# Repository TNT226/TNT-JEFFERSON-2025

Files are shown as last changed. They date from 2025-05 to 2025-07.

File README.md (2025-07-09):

# `TNT` - `KABOOM`

## Disclaimer
This repository is the same for the competition of the WRO 2025 Venezuela, and the WRO 2025 China.
There are two teams participating in the WRO competitions: one competing in WRO Venezuela made up of Nicola, Emiliana and Sara and another that will compete in WRO China made up of Nicola, Sara and Samantha.

## About

This repository provides information and knowledge regarding the current progress, evolution, and development of our self-driving robot vehicle for the World Robot Olympian (WRO) 2025 competition in the category Future Engineers, which is build and coded by us.

## TNT & Kaboom - WRO 2025 Future Engineers

The name of our team is TNT, we chose this name because we will _explode_ the comptetition with our hard work and dedication! On the other hand, Kaboom is the name of our autonomous robot, build by using 3d printing and arduino together. We are a group of Venezuelan high schoolers who yearn to learn and be masters in robotics. TNT also have plenty of objectives like:

* Obtain expertise and mastery in robotics, engineering and self-driven robots.
* Learning how to cooperate and work as a team to solve problems with ingenious, imaginative, and creative solutions.
* Acquire knowledge regarding new and old technologies, information about eletronics, hardware, software, and more.
* Gain experience for opportunities or competitions that we might face in the future.
* Win the competition and enjoy the process through this exciting road!

TNT is form by three members :

  - Nicola Pasquale Simone Perdomo 16YO
  - Sarah Virginia Quintana Arrieta 18YO
  - Emiliana Raquel Guerrero Fermín 16YO
  
One thing that defines us, TNT, is that unlike others, we _don't_ give up easily, we are determine to be the best and improve as much as possible, always looking for success and enjoying every part of the process. You can see this characteristic about us being really strong during "our journey, process and prototypes" below and in the `Older versions of our final robot` folder.

## Content

- `Pictures (Team and vehicle)`: contains photos of the final robot from different views and angles. And photos of us individually and in group.
- `Older versions of our final robot`: contains photos of our previous ideas and prototypes that eventually lead to the final design and robot, Kaboom.
- `Obstacle management`: contains the source code of the prototypes and the final robot with detailed comments, strategies, flowchart diagrams and pseudocode.
- `Videos`: contains links to our Youtube videos which show how our previous attempts turn out and function, and also how the final robot completes the challenges and more. 
- `Mobility management`: contains all the 3D printed models we used throught our journey, all the 3d pieces, electrical components, and materials used in the final robot, a brief discussion regarding the vehicle chassis design/selection as well as the mounting of all components to the vehicle chassis/structure, and more.
- `Power and sense management`: contains power and sense management about the power source for the vehicle as well as the sensors required to provide the vehicle with information to negotiate the different challenges, the reasons for selecting various sensors and how they are being used on the vehicle together and a wiring diagram with BOM that includes all aspects of professional wiring diagrams.

## Materials and components

What is Kaboom made of? Kaboom is made of pieces and blocks from a  aluminum alloy chassis and 3d printed parts from our 3d printer being the bambu lab P1S owned by Nicola Simone, while also using "ready to go" electrical components. We also used an Arduino UNO board as our main controller, since we saw that this is the most efficient way to complete the challenges.

|PIECES OUR ROBOT USES |3D PIECES/ARDUINO/ELECTRICAL COMPONENTS OUR ROBOT USES ARE:| 
|---|---|
|1x Yahboom DIY Smart Robot Chassis Ackerman Chassis|1x Gray 11.4V JGB37-520 Motor|
|1x Second Floor Platform 3d|1x Pixycam 2.1|
|1x Axis 3d|2x Ultrasound sensors|
|1x Carriage Axle Gear 3d| Arduino cables |
|1x Motor Gear|Alligator Cables|
|1x Motor Support 3d|1x Nihewo Batery 11.1V/7500mAh|
|1x Motor Support Stand 3d|1x Arduino Uno Board|
||1x Arduino Shield Protoboard|
||1x H-Bridge Module|
||1x Buck Module|
||1x Switch On-Off|

### To know the complete list of all the materials used visit the `Mobility management` folder.

## Our journey, progress and prototypes

In the beginning of our journey, we had plenty of various and diverse ideas on how to build our robot but eventually it all worked out. When we first started, we did messy sketches and tried a lot of ideas. Here are some of our first sketches and ideas for Terreneitor:



Eventually, with these sketches in mind, we started working on the physical robot. We had high hopes for our first prototype, and the more we worked on it, the more our hopes grew. But, there was a problem, a big one...if you see "First prototype wheels mechanism" (you can find in the `videos` folder) you might think, like us, that it would be super fast on the ground, however when we finally were ready to put it to the test... it failed. The wheels mechanism of this prototype did not work on the ground. We tried to change many things and pieces in this prototype to see if it would help, but all our work was in vain, the mechanism still did not work on the floor. Eventually, we find out the cause... the mechanism didn't work because the dc motor that we were using, eventhogh it was fast, it didn't have enough strength and power to move the gear mechanism (the robot was also really tall and heavy causing the dc motor to be carrying this weight all the time, since it was located on the lower part of it. Let's not forget to comment that, also the mechanism for the direction of the robot did not work out too because the motor couldn't move the mechanism (for a better visual understanding visit the `videos` folder), although that was a minor problem compare to the wheel mechanism problem.

But, not everything went wrong with our first prototype because we also did a circuit for the servomotor and for the wheels, and we had a base (constructed by us with lego). All of this things helped us, along with our previous mistakes, to improve and create our second prototype.

In our second prototype, since we learned from our failures and errors from the past prototype, it didn't had any enormous problem, however, there were still problems to be fixed. We realized that the two dc motors we had weren't working simultaneously, which violated the rules of the WRO 2024 competition and also that, eventhough the mesurements of the robot were good according to the rules, it was still, to big in width, which lead to problems like being too heavy so it went super slow (which you can see in the video "Second prototype on the track" in the `videos` folder). And a third
problem was that when we building this prototype was that it did not direct the robot correctly because the wheels of the front couldn't rotate to either left or right. 

As you can realize by now we had plenty of problems since the beginning, let's gather all of them:

### First prototype:

- The wheels mechanism did not work on the ground
- The direction mechanism did not work
- Heavy
- Tall

### Second prototype:

- The mechanism we were using for the wheels violated the rules of WRO 2024 competition
- Too big in width
- Too heavy
- Slow, due to the two previous problems
- Didn't direct the robot correctly
  
### Third prototype:

- The mechanism wasnt consist
- Low voltage on motor
- Problems on turns
- Didn't detect colors right
  
### *(to learn more about our sketches and prototypes go to the `Older versions of our final robot` folder)*

### Final robot

Journies have downsides and good times, advantages and disavantages. After the first and second prototype you might think that because of all this problems we might give up, but contrary to this hypothesis, we didn't (after all "third time's a charm", right?), instead we improved and our mistakes made us stronger, wiser and smarter. So when we created our final robot, we made sure to not make any of our previous mistakes, being very causious in its construction. Thanks to this, we have a robot that is:

- Light weighted
- Tall and thin
- The direction and wheel mechanism do work
- Fast
- Solid chassis
- 3d printed parts designed by us
- Doesn't violate any rules of the WRO 2025 competition.

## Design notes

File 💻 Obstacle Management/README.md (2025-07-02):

# Obstacle management

In this directory you will find:
- the software we used to make our code
- all the code we used for our prototypes and the final robot
- our source code with detailed comments
- our pseudo code
- all the strategies our robot uses in order to complete the open challenge round and the obstacle challenge round
- our old and new flowchart diagram 

## Software

The software we used for coding and programming our robot, Kaboom, is _Arduino Integrated Development Environment (IDE)  _ application version: 2.3.2 in MacOS. Arduino uses a variant of the C++ programming language. The Arduino Integrated Development Environment or Arduino Software (IDE)  contains a text editor for writing code, a message area, a text console, a toolbar with buttons for common functions and a series of menus. It connects to the Arduino hardware to upload programs and communicate with them. We chose using this software not only because of its simplicity but because it what we learned in our school.



##  Pseudocode and strategy

A pseudocode is a representation of code used to demonstrate the implementation of an algorithm without actually doing so. It often acts as a rough draft of coding projects, and is written in an explainable manner to be understandable by programmers at any knowledge level. Meanwhile, a strategy, in this case, is our plan to achieve our goals during the challenges and rounds of the WRO 2024 future engineers competition. Here is our pseudo code and strategy explained in detailed for each round:

### Round 1:

This pseudocode outlines the operational logic for our robot, focusing on basic movement, obstacle avoidance, and lap tracking.

**Step 1: Initialization**

* Start the JGB37-520 motor.

* Begin moving the car straight forward.

* Initialize the turn counter to zero.

**Step 2: Continuous Movement and Obstacle Detection**

* Continue moving straight forward until an ultrasonic sensor detects a distance greater than the length between the black boards in the track.

**Step 3: Directional Adjustment Based on Proximity**

* **If the distance detected by an ultrasonic sensor is less than a predefined threshold from either side, the robot will initiate a turn (right or left).**

* **If the left wall is closer to the robot than the right wall:**

   * Turn the robot to the right side.

* **Else (if the right wall is closer to the robot than the left wall):**

   * Turn the robot to the left side.

**Step 4: Lap Tracking and Round Termination**

* **After the robot completes 12 turns (which signifies 3 laps):**

   * Stop the robot at its starting position.

   * End the round/challenge.

* **If the robot has not yet completed 12 turns (3 laps):**

   * Continue operating until all 3 laps are completed and the round/challenge ends.

### Round 2:
This pseudocode is the same as the one used for the first round. The only difference is that the rectangular box in the center is now moved slightly to either side of the track, but the underlying mechanism remains the same.

**Step 1: Initialization**

* Start the JGB37-520 motor.

* Begin moving the car straight forward.

* Initialize the turn counter to zero.

**Step 2: Continuous Movement and Obstacle Detection**

* Continue moving straight forward until an ultrasonic sensor detects a distance greater than the length between the black boards in the track.

**Step 3: Directional Adjustment Based on Proximity**

* **If the distance detected by an ultrasonic sensor is less than a predefined threshold from either side, the robot will initiate a turn (right or left).**

* **If the left wall is closer to the robot than the right wall:**

   * Turn the robot to the right side.

* **Else (if the right wall is closer to the robot than the left wall):**

   * Turn the robot to the left side.

**Step 4: Lap Tracking and Round Termination**

* **After the robot completes 12 turns (which signifies 3 laps):**

   * Stop the robot at its starting position.

   * End the round/challenge.

* **If the robot has not yet completed 12 turns (3 laps):**

   * Continue operating until all 3 laps are completed and the round/challenge ends.

### Round 3:
This pseudocode outlines the operational logic for our robot, integrating both obstacle avoidance with ultrasonic sensors and color-based navigation using the Pixy camera.

**Step 1: Initialize Robot and Begin Movement**
* Start the JGB37-520 motor.
* Begin moving the car straight forward.
* Initialize turn counter for special color detection to zero.

**Step 2: Continuous Sensor Readings**
* Continuously read data from both ultrasonic sensors to determine distances to surrounding walls.
* Continuously check the Pixy camera for color detection.

**Step 3: Color-Based Navigation (Prioritized)**
* **If the Pixy camera detects a Green obstacle:**
    * Turn the robot to the **left**.
* **If the Pixy camera detects a Red obstacle:**
    * Turn the robot to the **right**.
* **If the Pixy camera detects the Special (Magenta) color:**
    * Increment the turn counter (lap counter).
    * If the turn counter reaches 3 (meaning 3 laps are completed):
        * Stop the robot permanently (park in the magenta parking lot).
        * End the round/challenge.
    * If the turn counter has not reached 3, continue normal operation.

**Step 4: Ultrasonic-Based Obstacle Avoidance (When No Color Detected)**
* **If no color is currently detected by the Pixy camera:**
    * **If both ultrasonic sensors detect walls:**
        * Continue moving straight forward.
    * **If the left ultrasonic sensor detects open space (distance > 50 cm):**
        * Turn the robot to the **left**.
    * **If the right ultrasonic sensor detects open space (distance > 50 cm):**
        * Turn the robot to the **right**.
    * **If the distance detected by one wall is significantly closer than the other (e.g., one side is < 50 cm and the other is > 50 cm):**
        * If the **left wall** is closer to the robot than the right wall:
            * Turn the robot to the **right** (to move away from the left wall).
        * Else (if the **right wall** is closer to the robot than the left wall):
            * Turn the robot to the **left** (to move away from the right wall).

**Step 5: Repeat**
* Continuously repeat Steps 2, 3, and 4 until the round ends (e.g., 3 laps are completed or the challenge time expires).

------------------------------------------

In order to explain all of the above better, we designed a flowchart diagram, a visual representation that depicts our process, system, computer algorithm, and a brief summary of how our code of the robot works on the track. During our journey we created two flowcharts as you can see below. The difference between the two diagrams is that the old one wasn't a good flowchart and didn't completely follow all the rules of a flowchart diagram and didn't explained correctly how our code and process works, on the other hand, our new flowchart diagram, does follow all the rules and conditions of a new flowchart diagram and explains correctly how our code and process works.
 
(both diagrams were created entirely by us, TNT, using the smartdraw website: https://www.smartdraw.com/flowchart/flowchart-maker.htm)

|Our Old Flowchart Diagrams|
|--------------------------|
|1st Flowchart Diagramando Model|
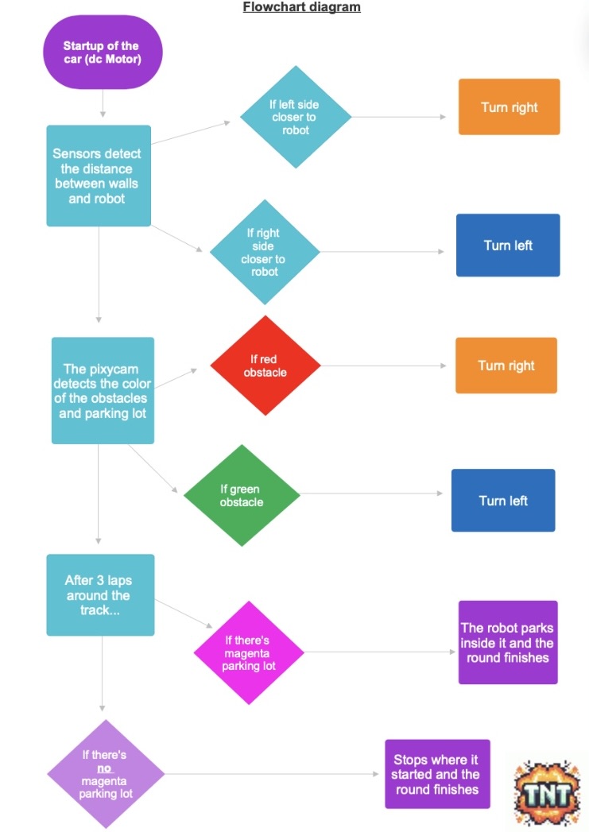
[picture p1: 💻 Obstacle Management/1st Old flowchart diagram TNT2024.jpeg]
||
|--------------------------|
|2nd Flowchart Diagramando Model|
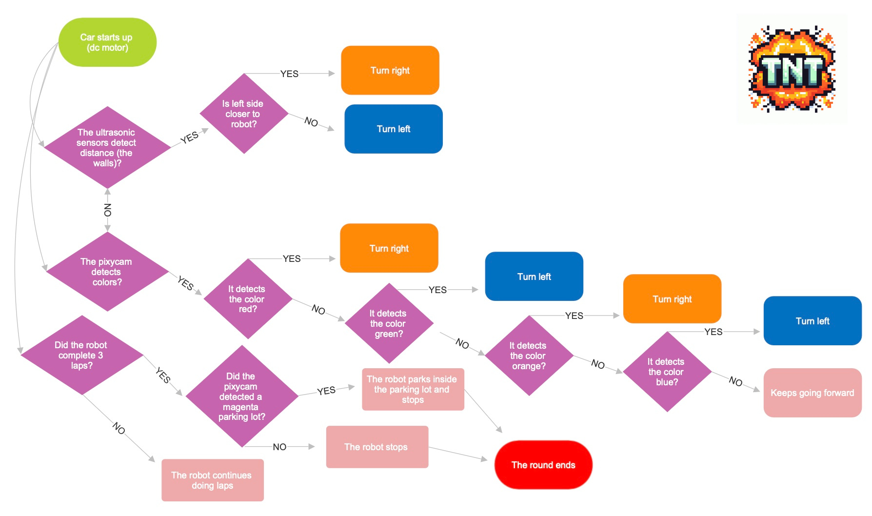
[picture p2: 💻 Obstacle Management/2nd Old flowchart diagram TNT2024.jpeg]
||

|Our New Flowchart Diagram|
|-----------|
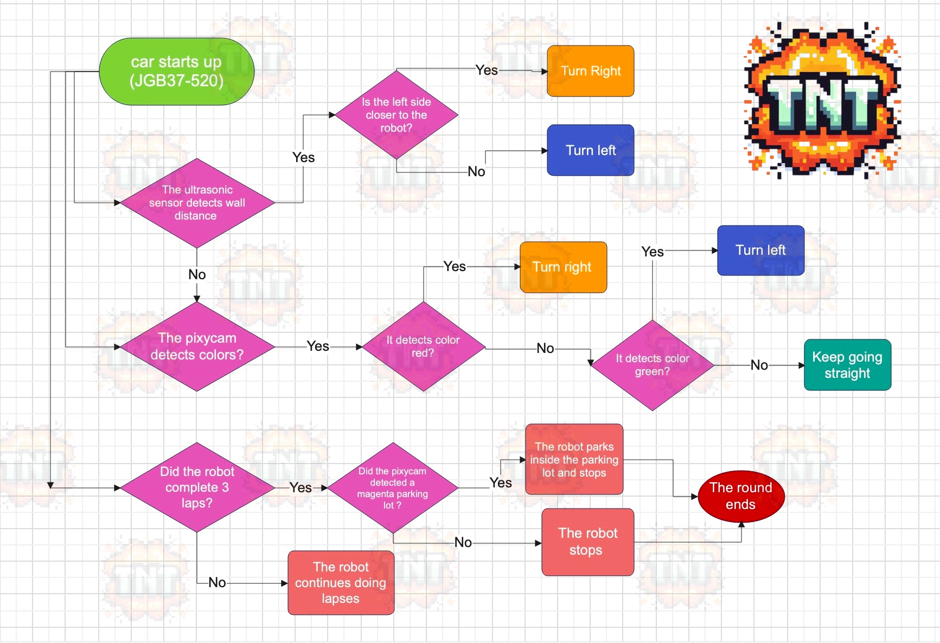
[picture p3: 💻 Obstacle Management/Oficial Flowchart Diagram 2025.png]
||

In this directory we uploaded all the codes we used both for our prototytpes and the final robot. All of this source codes contain detailed comments, so make sure to check them thoroughly!

Below you have a brief summary, pseudocode and strategies used in each indivual file and code:

## Code for First and Second Round (Open Challenge Round)

This code is specifically designed for the first round, also known as the open challenge round, of the competition. To understand its functionality in detail, please refer to the file named "First Round Code.ino" located in the designated folder. Within that file, you will find not only the code itself but also a comprehensive pseudocode explanation, breaking down each line step by step.

## Code for Third Round (Obstacle Challenge Round)

This code works for the second round, if you want to know what it is about check the file in the folder that's named "Second Round Code.ino", since the detailed comments will tell you what it is about.

## Code for the servomotor and ultrasonic sensors:

The code "Code for the servomotor and ultrasonic sensors.ino" enables the coordinated operation of our robot's steering mechanism and its two ultrasonic sensors. Within this file, you will find not only the code itself but also a detailed explanation, complete with its corresponding pseudocode.

The mechanism operates as follows:

- If the robot detects that one side is more than 50 cm away, it moves in that direction.

- If the robot detects that one side is less than 50 cm away, it moves in the opposite direction.

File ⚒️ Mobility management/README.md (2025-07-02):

# Mobility management

**Selection and Implementation of the Ackermann Chassis for Our Robotic Vehicle**

The decision to use an open Ackermann chassis for our vehicle was driven by several key factors related to functionality, space optimization, and modularity. The Ackermann steering geometry was chosen specifically because it provides improved turning efficiency and stability compared to simpler differential steering systems, making it ideal for precise navigation and maneuverability in our application. This design ensures that the inner and outer wheels follow different turning radii, minimizing tire scrub and improving overall control—a critical advantage for a vehicle carrying multiple electronic components.

**Structural Design and Platform Configuration**

The implementation of our chassis required two distinct platforms due to spatial constraints and component organization needs. A single platform would have made the vehicle excessively long, violating the size limitations set for our project.

***Primary Platform (Pre-fabricated Chassis Base):***

This platform came as part of the commercially available Ackermann chassis kit and serves as the structural foundation. It houses:
-The steering servo motor, which controls the front wheels via the Ackermann linkage.
-The JGB37-520 drive motor, mounted to power the rear wheels, providing sufficient torque and speed for movement.
-The Nihewo battery pack, positioned for optimal weight distribution.
-Additional 3D-printed brackets and supports designed by our team to secure components effectively.

***Secondary Platform (Custom 3D-Printed Add-On):***

To accommodate the remaining electronics without overextending the chassis length, we designed and fabricated a second platform that attaches to the primary structure using four metal support pillars (included in the original chassis kit). This elevated platform contains:
-The Arduino Uno (with motor shield) acting as the central control unit.
-An H-Bridge module for bidirectional motor control.
-A Buck converter module to regulate voltage for sensitive components.
-Two ultrasonic sensors for obstacle detection.
-A PixyCam mounted on a custom 3D-printed stand, enabling vision-based navigation.

***Advantages of the Dual-Platform Approach***

The design of the system prioritizes both ease of use and optimal performance through its modular and accessible structure. By separating mechanical and electronic components onto different platforms, maintenance and debugging processes are significantly streamlined, allowing for quicker identification and resolution of issues. This stacked configuration also greatly benefits weight distribution, as the lower platform houses heavier elements like motors and batteries, thereby lowering the center of gravity and enhancing overall stability. Furthermore, the upper platform is intentionally designed with expandability in mind, providing ample space for future integrations such as additional sensors or wireless communication modules. This thoughtful arrangement ensures that the system not only complies with size limitations but also maximizes its functional capabilities within those constraints.

***Why Ackermann Steering?***

The team opted for an Ackermann steering mechanism over simpler designs like skid-steer due to its inherent advantages in vehicle dynamics. Ackermann steering significantly reduces lateral tire slippage during turns, leading to improved energy conservation and enhanced traction. This sophisticated geometry also ensures predictable handling, which is crucial for precise algorithmic control in tasks like path planning. Furthermore, the design offers greater scalability, allowing for adaptation to higher speeds or larger vehicle sizes without compromising stability. However, integrating this more complex system presented its own set of challenges. Component interference was a key concern, as the servo's movement necessitated careful placement to avoid collisions with the upper platform. This was successfully addressed by adjusting pillar heights and optimizing the servo's mounting angle. Additionally, vibration damping was essential, and the 3D-printed platform was reinforced with ribbing to prevent flexing during operation. Finally, meticulous wiring management was implemented, with cables routed through the pillars to minimize tangling and mitigate potential electromagnetic interference, ensuring reliable performance.

By leveraging the Ackermann chassis’s mechanical advantages and augmenting it with a custom 3D-printed secondary platform, we achieved a compact, high-performance robotic vehicle. This design not only meets spatial and functional requirements but also provides a robust framework for future upgrades, demonstrating the synergy between off-the-shelf components and tailored engineering solutions.

# About the Engine

We selected the JGB37-520 motor for our project due to its considerable power and high-speed performance, making it an ideal choice for efficiently driving our vehicle. After evaluating several motor options, we chose this model because it provides the right balance of torque and RPM to ensure smooth and reliable movement while maintaining energy efficiency. To mount the motor securely, we designed a custom 3D-printed bracket that holds it firmly in place at the bottom of the car’s chassis. This bracket was bolted down to prevent any unwanted vibrations or misalignment during operation. The motor is equipped with a gear mechanism that meshes with another gear connected to the rear axle, effectively transferring rotational force to the wheels. This direct-drive setup ensures optimal power transmission, allowing the rear wheels to propel the vehicle forward with consistent speed and control. The implementation was carefully tested to ensure proper gear alignment and minimal friction, maximizing the motor’s efficiency and longevity. Overall, the JGB37-520 motor, combined with our mounting solution and drivetrain design, provides a robust and reliable propulsion system for our car.

We powered the system with an 11.1 V Nihewo battery. However, a buck voltage regulator was required because the battery voltage was too high for the servomotor's requirements. We specifically set the buck regulator to 7 V, as the servomotor's maximum voltage is 7.4 V. This same battery is also connected via cables to the H-bridge, which supplies power to both the Arduino board and the car's main propulsion motor. The H-bridge provides 12 V to the car's propulsion system and 5 V to the Arduino board. Consequently, the remaining accessories, the two ultrasonic sensors and the Pixycam, are connected directly to the Arduino board pins and programmed through it.

For steering, as previously mentioned, we are using a 20 kg·cm servomotor. This component was included with the Ackerman chassis we purchased. It will be connected to the Arduino to control the car's direction and to the Buck module to regulate the voltage flow.

For the main controller, we opted for an Arduino Uno board. The primary reason for this choice is its efficiency in programming the car and its accessories compared to other controllers. Additionally, the Arduino's programming language is C++, which is the language taught at our school.

# Engineering Principles:

### **Horse Power**  
Power, as a fundamental engineering principle, determines the motor's capacity to perform work over time, and the JGB37-520 motor (12V) delivers 10-15W (0.013-0.02 HP) at rated speed—an optimal range for compact robotic applications that balances performance with energy efficiency. This power output enables the motor to overcome friction, inertia, and load resistance while maintaining consistent movement, crucial for our chassis's reliable operation. The motor's power curve reveals peak efficiency at 50-70% of maximum RPM (~130 RPM no-load speed), where it achieves the best mechanical-to-electrical power ratio, ensuring smooth acceleration and sustained motion.

The 12V supply voltage plays a key role in maintaining stable power delivery, preventing voltage sag under load while keeping the motor within safe thermal limits. Although modest in absolute terms, this power rating is carefully engineered to provide sufficient thrust without excessive bulk, thanks to its optimized power density (W/kg). Power is intrinsically linked to torque and RPM—while the motor's wattage ensures continuous operation, the gear system (when considered) efficiently transmits and amplifies this power to the wheels, preventing stalling or performance drops under resistance. Without adequate power management, the system would struggle with efficiency and heat dissipation, highlighting why the JGB37-520's balanced output is critical for long-term reliability in small-scale electromechanical applications.

### **Speed**  
Speed refers to how fast the motor’s output shaft rotates, measured in revolutions per minute (RPM), and directly impacts how quickly the car moves. The JGB37-520 motor provides a high RPM, which is then adjusted by the gear ratio to balance speed and torque. A higher gear ratio (more teeth on the driven gear) increases torque but reduces speed, while a lower ratio does the opposite. In our design, the gear connection between the motor and axle ensures an optimal balance—enough speed for swift movement while maintaining sufficient torque to prevent wheel slippage. Proper speed control is crucial for stability, especially when navigating turns or uneven surfaces.  

### **Torque (Rotational Force)**  
**Torque Characteristics and System Performance of the JGB37-520 Motor**  

The JGB37-520 motor (12V version) serves as the core of our propulsion system, delivering a rated torque of 0.7 kg·cm (0.068 N·m) under normal operation—a crucial rotational force that overcomes static friction, inertia, and drivetrain resistance to enable smooth acceleration from rest. When subjected to extreme loads, its stall torque peaks at 2.5 kg·cm (0.245 N·m), providing vital overload protection against sudden resistance spikes while preventing motor stalling. This torque capability ensures the chassis maintains motion despite friction and weight, particularly important when navigating inclines or during rapid acceleration.  

While the motor's modest power output (10-15W or 0.013-0.02 HP) might seem limiting, the system compensates through intelligent mechanical optimization. The gear reduction mechanism (where a smaller motor gear drives a larger axle gear) strategically converts excess RPM into multiplied torque, prioritizing usable force over raw speed. This mechanical advantage ensures the rear wheels receive optimized thrust without overburdening the motor, while the 12V power supply maintains an efficient balance between speed potential and torque delivery. The result is a responsive drivetrain where torque effectively handles challenging conditions like inclines and acceleration, while the carefully matched power output prevents energy waste—demonstrating how precise torque management is fundamental to electromechanical system performance. Without this careful equilibrium between torque generation and power application, the system would face efficiency losses and operational challenges under load.

### **Gear Mechanics (Power Transmission & Efficiency)**  
Gears are crucial for transferring power from the motor to the wheels while optimizing efficiency. In our design, the motor’s gear meshes with a larger gear on the axle, creating a speed reduction system that trades some RPM for increased torque. This mechanical advantage ensures smoother acceleration and better load handling. Additionally, the 3D-printed mounting bracket keeps the gears properly aligned, minimizing energy loss due to friction or misalignment. Efficient gear design reduces wear, improves battery life, and ensures reliable performance. Without an effective gear system, much of the motor’s energy would be wasted, leading to poor traction and sluggish movement.  

By carefully balancing power, speed, torque, and gear mechanics, our chassis achieves an efficient and reliable drivetrain, demonstrating key engineering principles in motion control and mechanical design.
Here is our scheme of conduction and direction of our robot:

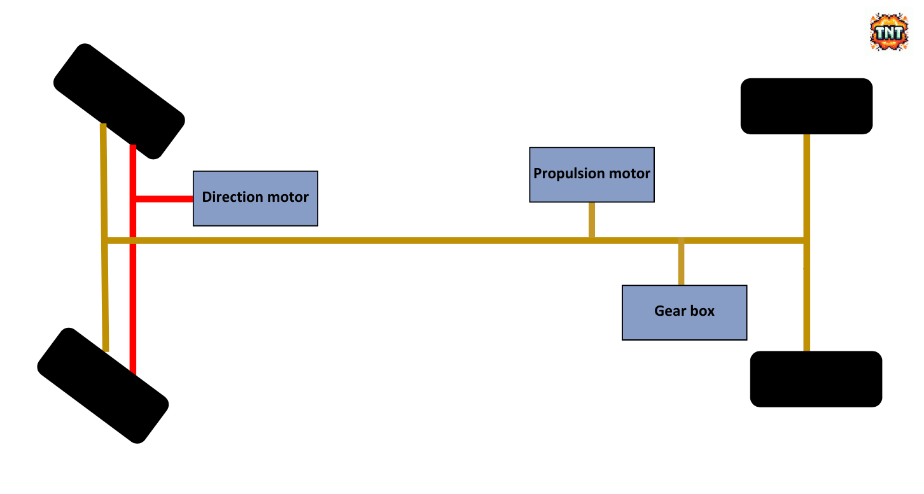
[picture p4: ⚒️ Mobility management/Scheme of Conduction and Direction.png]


# Build

In the chart below titled "THE "READY TO GO" ELECTRICAL COMPONENTS OUR ROBOT USES ARE:", you will find:

First, the amount of that especific piece we used on the robot
Second, the name of that "ready to go" electrical piece/component

|THE "READY TO GO" ELECTRICAL COMPONENTS OUR ROBOT USES ARE:|Photo of Each:|
|---|---|
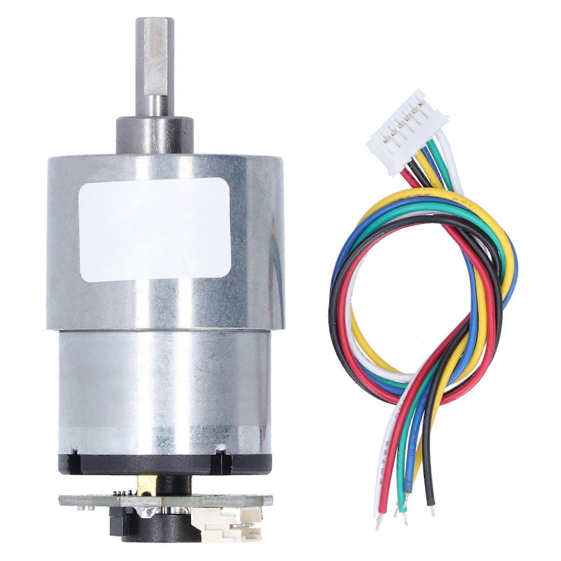
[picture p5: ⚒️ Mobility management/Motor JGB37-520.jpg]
|1x Gray 11.4V JGB37-520 Motor||
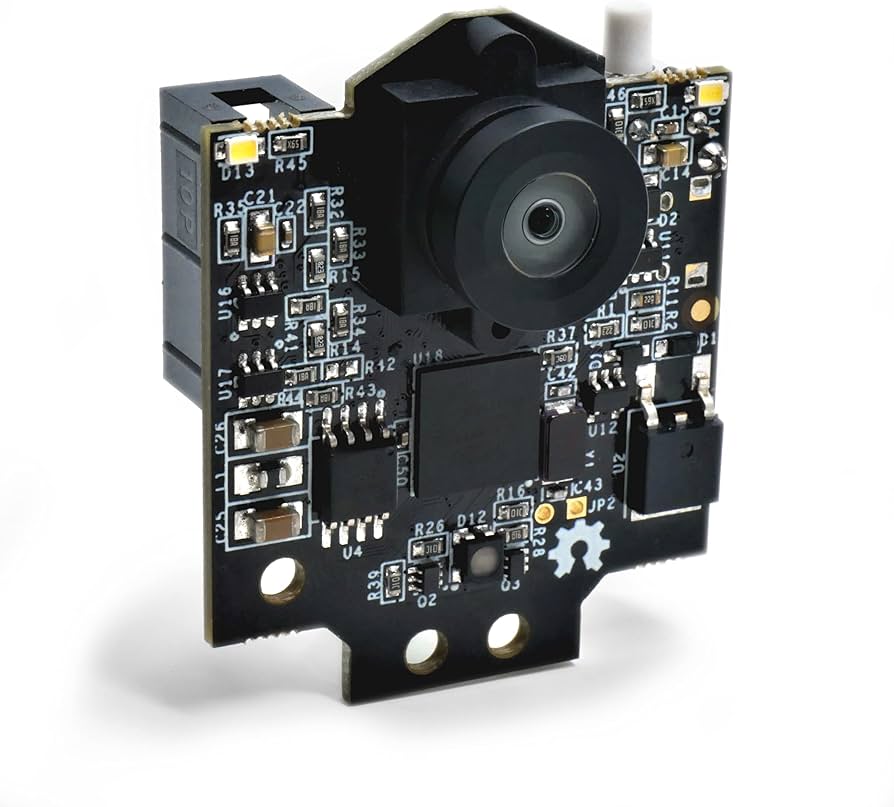
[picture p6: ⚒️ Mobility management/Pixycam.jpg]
|1x Pixycam 2.1||
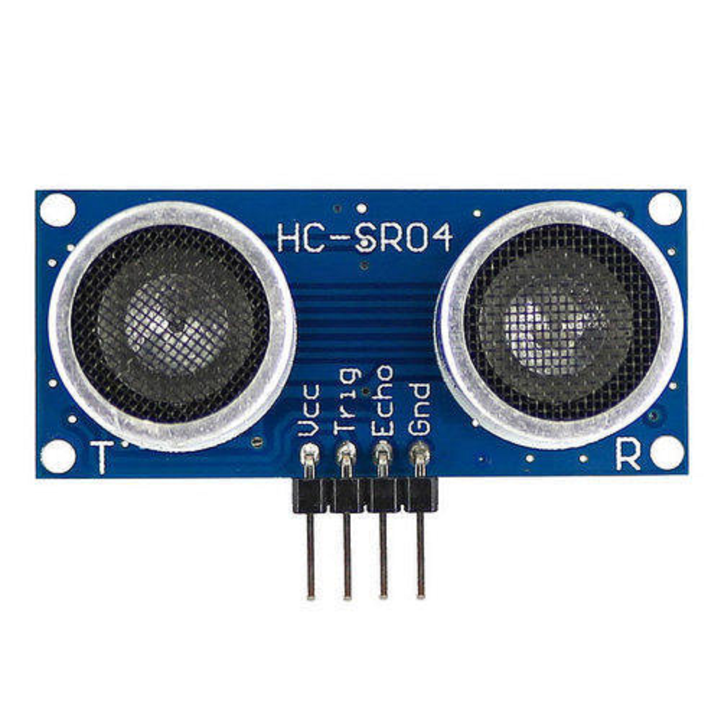
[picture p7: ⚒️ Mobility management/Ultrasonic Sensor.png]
|2x Ultrasound sensors||
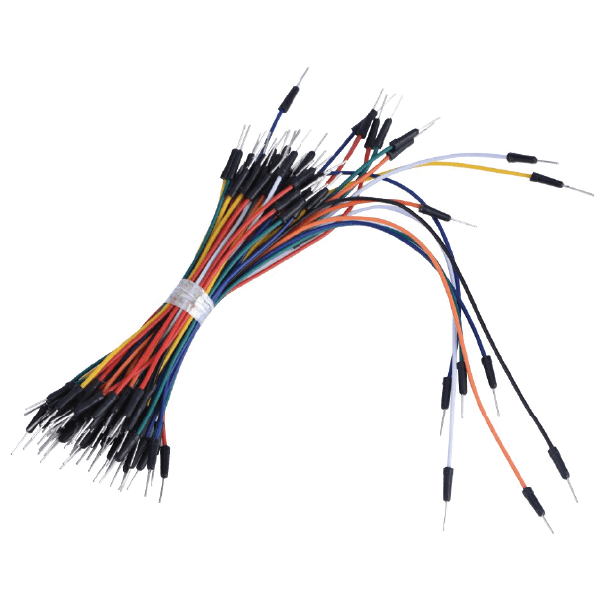
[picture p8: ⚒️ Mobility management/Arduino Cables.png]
|Many Arduino cables ||
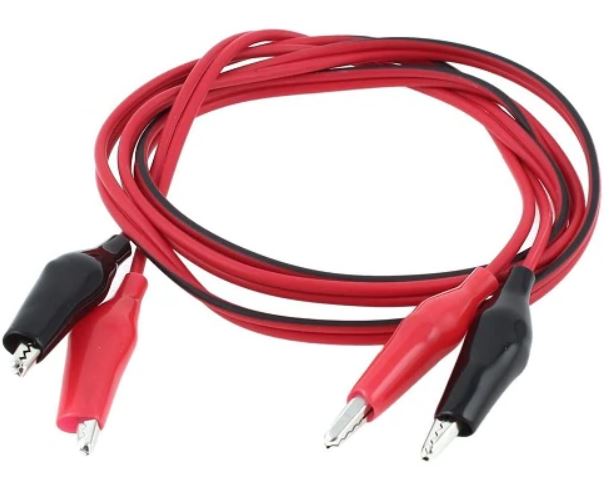
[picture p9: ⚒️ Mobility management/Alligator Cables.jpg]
|Many Alligator Cables||
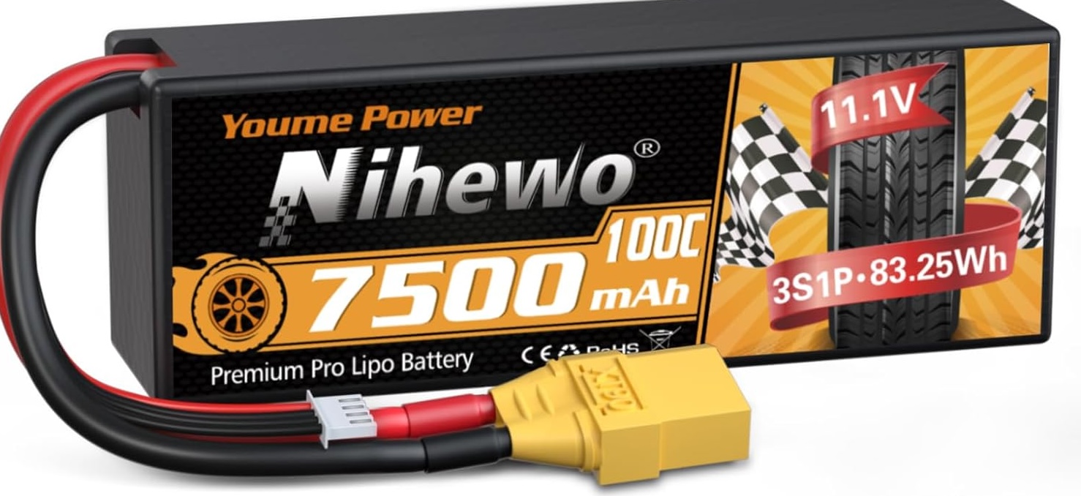
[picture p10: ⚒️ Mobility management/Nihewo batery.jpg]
|1x Nihewo Batery 11.1V/7500mAh||
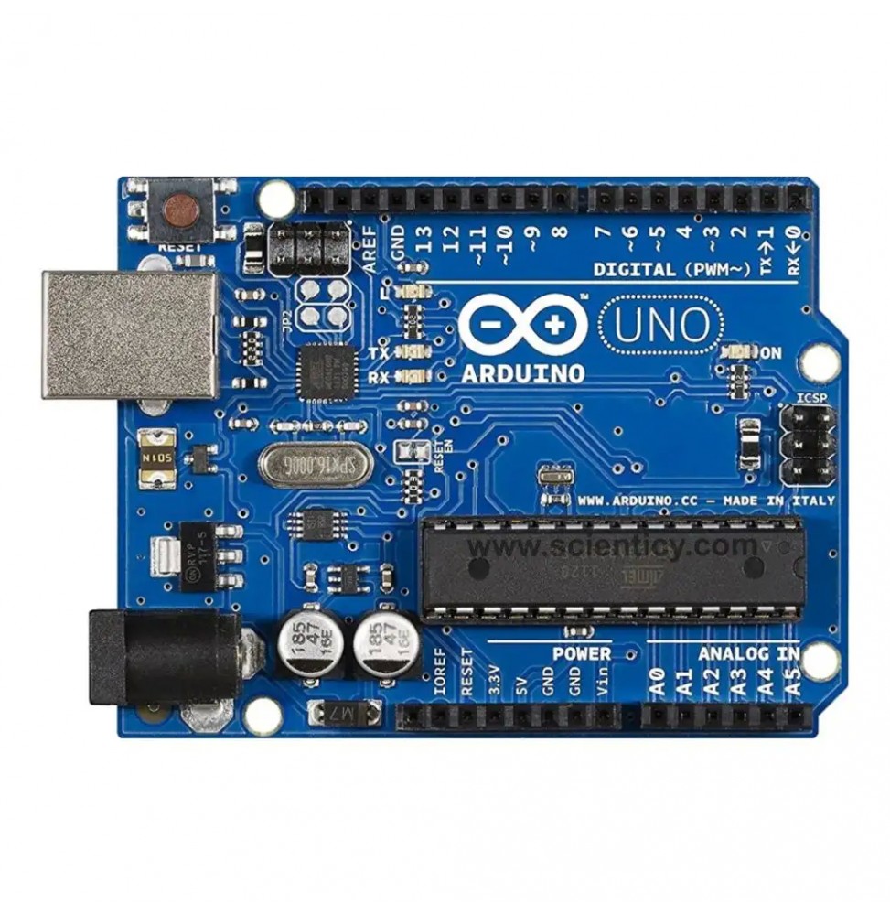
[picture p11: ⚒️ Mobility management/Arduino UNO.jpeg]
|1x Arduino Uno Board||
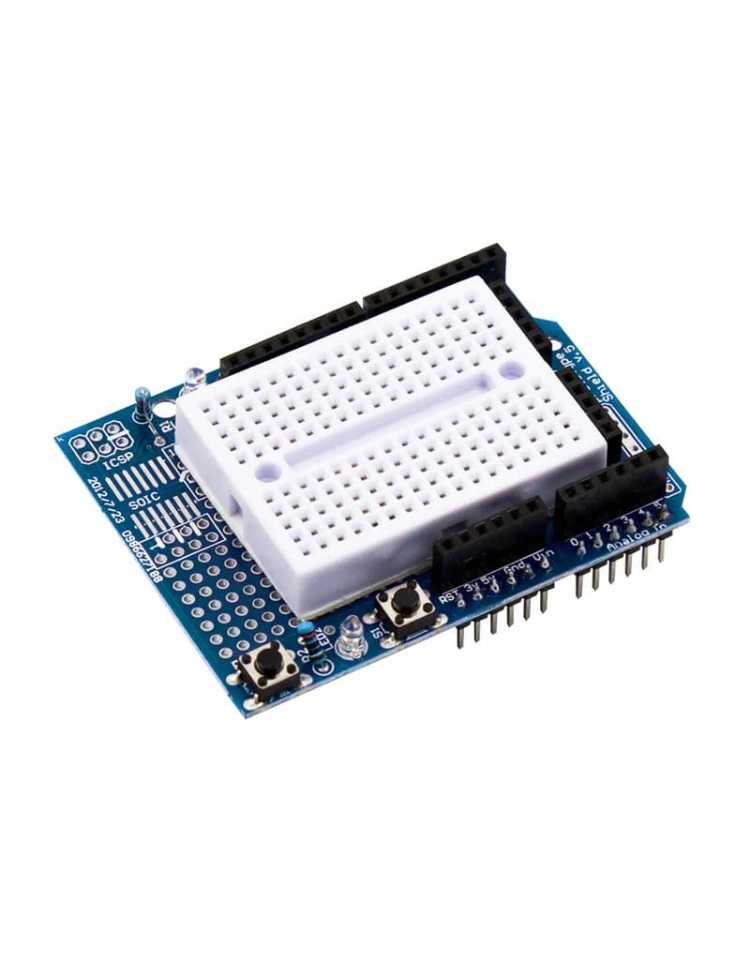
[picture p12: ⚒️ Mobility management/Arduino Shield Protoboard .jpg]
|1x Arduino Shield Protoboard||
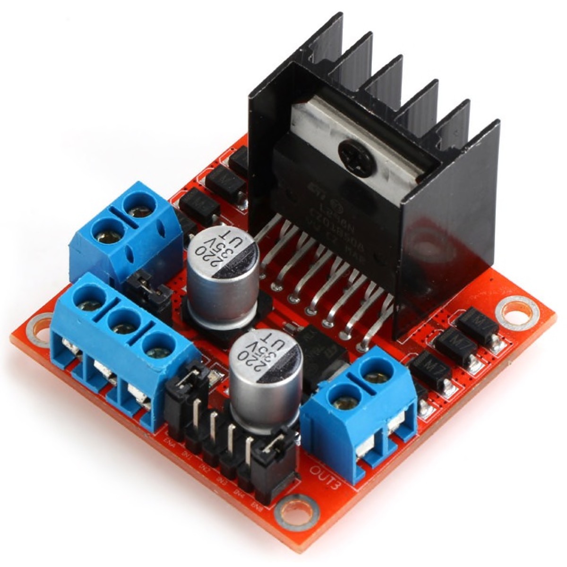
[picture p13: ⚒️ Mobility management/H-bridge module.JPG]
|1x H-Bridge Module||
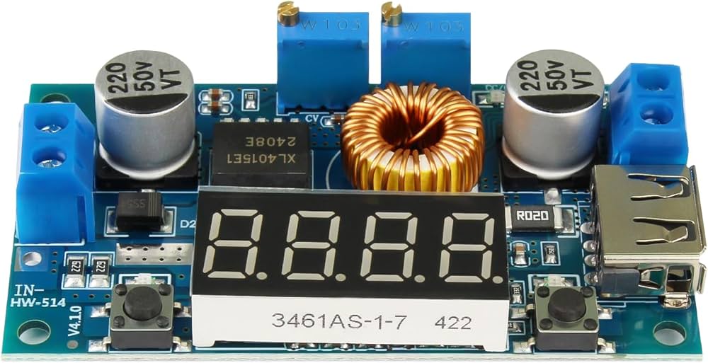
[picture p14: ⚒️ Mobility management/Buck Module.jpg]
|1x Buck Module||
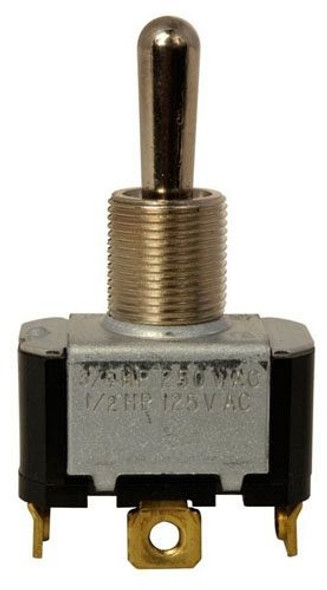
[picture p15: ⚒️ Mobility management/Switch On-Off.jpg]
|1x Switch On-Off||
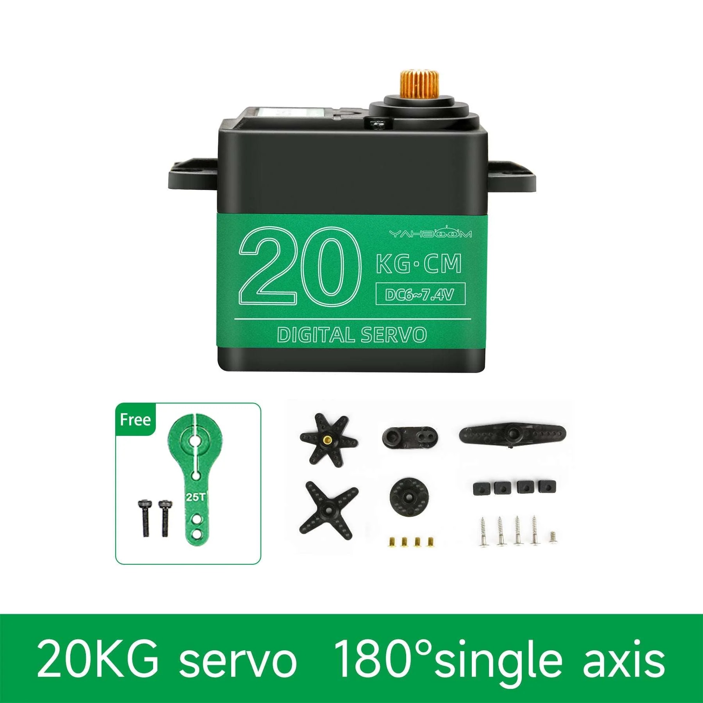
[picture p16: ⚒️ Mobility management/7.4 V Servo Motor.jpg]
|1x Servo Motor 7.4V||

|OTHER MATERIALS OUR ROBOT USES ARE:|Photo of each:| 
|---|---|
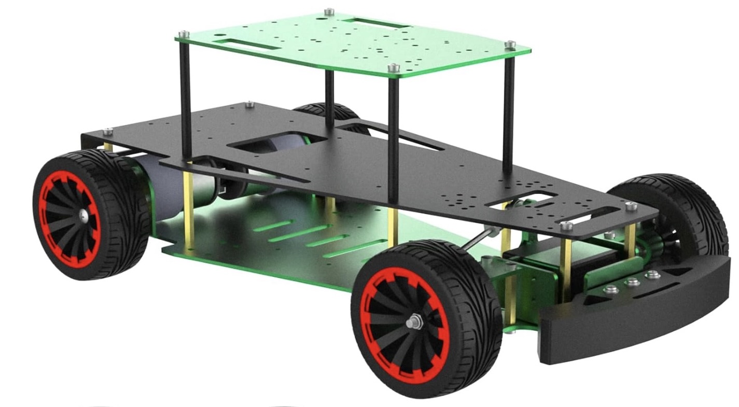
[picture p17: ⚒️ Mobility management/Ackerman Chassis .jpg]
|1x Yahboom DIY Smart Robot Chassis Ackerman Chassis||
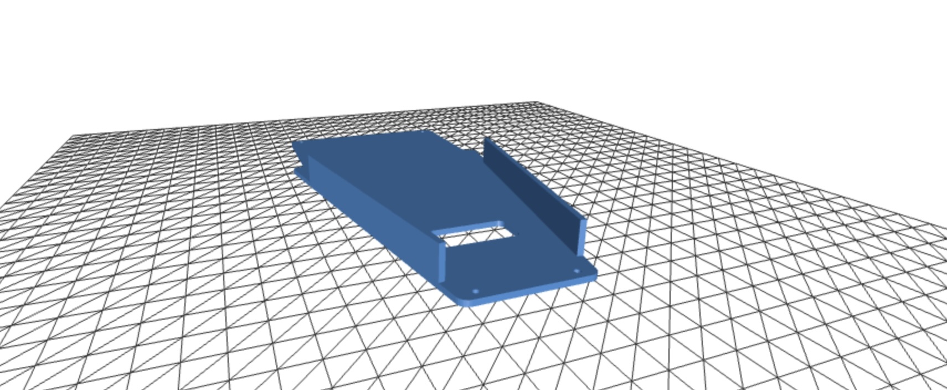
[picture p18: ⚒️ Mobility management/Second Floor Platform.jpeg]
|1x Second Floor Platform 3d||
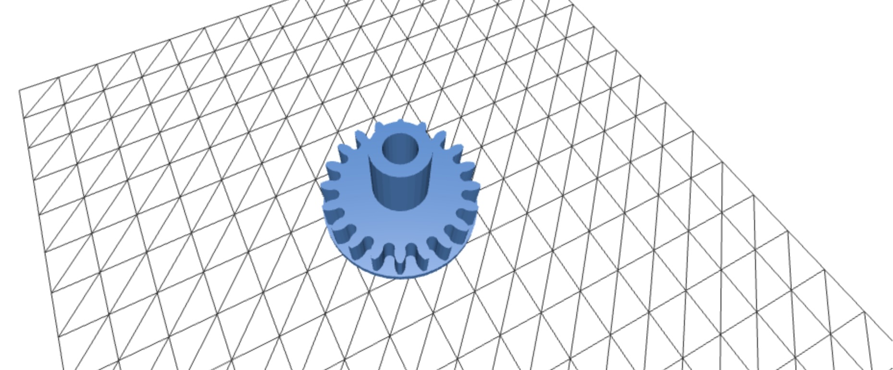
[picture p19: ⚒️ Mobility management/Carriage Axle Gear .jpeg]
|1x Carriage Axle Gear 3d| |
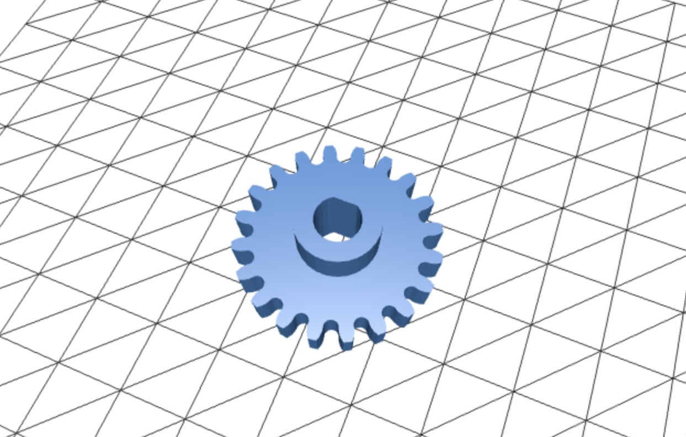
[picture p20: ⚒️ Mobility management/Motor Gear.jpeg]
|1x Motor Gear||
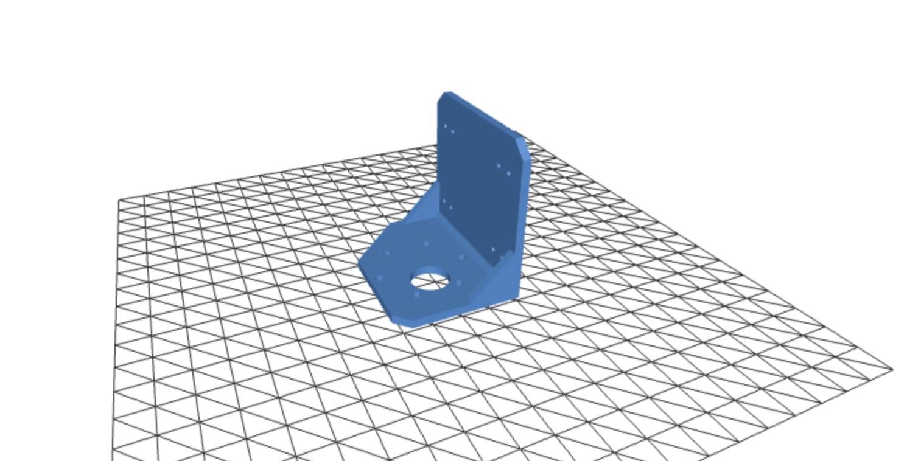
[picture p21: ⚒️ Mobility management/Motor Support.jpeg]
|1x Motor Support 3d||
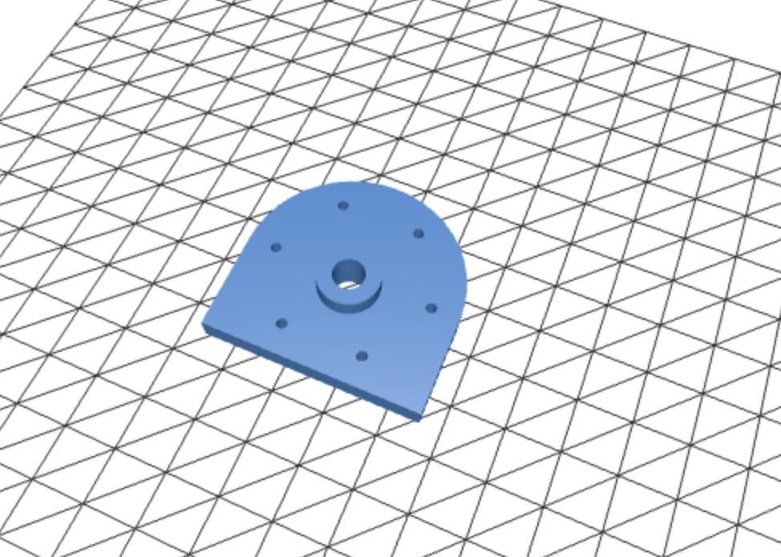
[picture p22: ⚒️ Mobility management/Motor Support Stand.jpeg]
|1x Motor Support Stand 3d||
|1x Axis 3d||

## Why did we chose all of these previous materials?
We chose all of these previous materials, components and pieces in our robot because is what we found in our robotics laboratory in school and it is what we are being taught.

Absolutely everything (the "ready to go" electrical components and the 3d printed parts) were bought, and in case of the 3d parts designed and printed, here in our country, Venezuela, except for the pixycam and the ackerman chassis which where imported from abroad.

## Note:
Most of what we've described is integrated into our final robot. However, for our previous attempts and prototypes, we utilized largely the same materials, pieces, parts, and components. It's worth noting that since this is our second year competing, many of our prototypes are carried over from last year.

# #Models:
Now, we will talk about all the information regarding our 3D printed models, designed and printed by us.

# Our 3D printers
It is important to mention that we own a Bambú Lab P1s 3d printer, which is a fundametal part in the creation of our robot.

|Printer:|Photo:| 
|---|---|
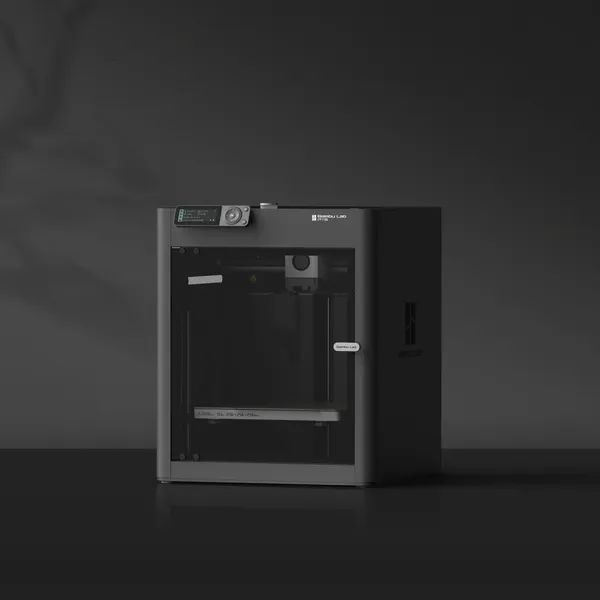
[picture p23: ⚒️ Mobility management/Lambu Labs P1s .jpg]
|Lambu Labs P1s||

## Green and red obstacles
This model counts with two pieces: the first one being red and the second one being green. This pieces help us practice for the second round (obstacle challenge).
|Object|Photo of each:| 
|---|---|
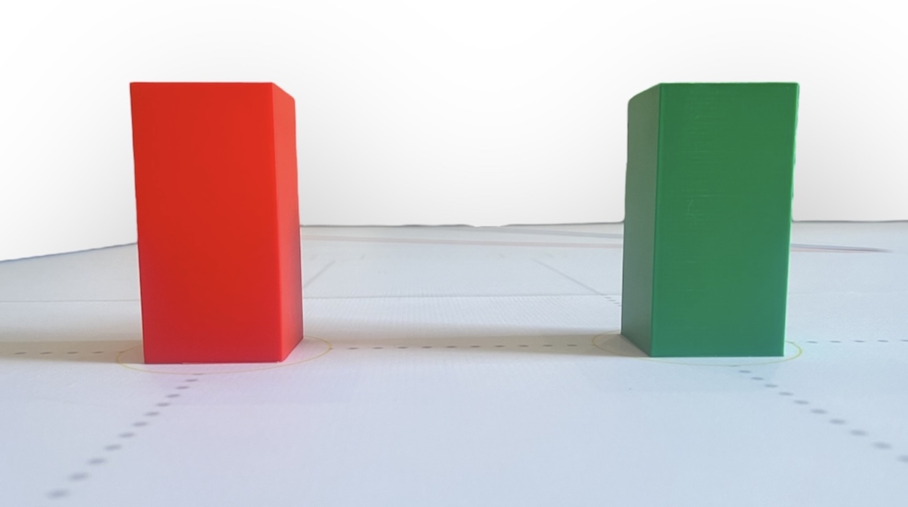
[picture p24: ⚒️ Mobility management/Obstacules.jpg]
|Obstacules (Red and Green)||

### (you can find the 3D model stl document in this folder)

## Gears
For the gears, we designed two models the Carriage Axle Gear and the Motor Gear, which are attached to the axis (that we also designed) and to the motor.
|Name of Gear:|Photo of each:| 
|---|---|
|Motor Gear||
|Carriage Axle Gear||

## Making Kaboom Step by Step:

**Step 1:** Upon receiving the Yahboom DIY Smart Robot Chassis Ackerman Chassis, our initial modification involved a crucial adjustment to its overall length. To ensure full compliance with the competition's dimensional regulations, we carefully measured and then precisely cut the existing chassis in half. This modification was not arbitrary; it was a deliberate engineering decision to bring the robot's footprint within the prescribed limits, which are often stringent in robotics competitions. By reducing the chassis's length, we aimed to maintain the integrity of the Ackerman steering geometry while achieving the necessary compactness for optimal performance within the confined competition area. This foundational step was essential for all subsequent assembly and integration processes.



**Step 2:** Following the chassis length adjustment, our next critical step involved the creation and integration of custom motor stands. Recognizing the need for precise and secure mounting points for our drive motors, we leveraged 3D printing technology to design and fabricate these essential components. The design process for these stands considered factors such as optimal motor alignment, stability under load, and ease of assembly. Once printed, these newly manufactured motor stands were then meticulously screwed onto the existing black stands at the rear of the chassis. This strategic placement ensures that the motors are firmly anchored, minimizing vibration and maximizing power transfer to the wheels, which is vital for both efficient movement and accurate control during the competition. This approach allowed us to customize the chassis to our exact specifications, providing a robust and tailored foundation for the robot's propulsion system.



**Step 3:** Having completed the structural modification of the chassis and prepared the motor stands, the third crucial step involved securely integrating our primary drive motor onto the main platform. This process required careful alignment of the motor with its custom-designed 3D-printed support, which we had previously screwed to the back stands. The motor and its support were then firmly attached to the main chassis platform using appropriate fasteners. This robust attachment is paramount for the robot's performance, as it ensures that the motor's power is efficiently transferred to the wheels without any loss due to instability or misalignment. The secure mounting also helps in minimizing vibrations during operation, contributing to smoother movement and more precise control, which are vital for successfully completing the competition's challenges.



**Step 4:** After securely mounting the motor to the chassis, the fourth step focused on the crucial assembly of the drive train: integrating the axis and gears with the motor and its corresponding gear. This process began by carefully fitting the main drive axis through the designated bearings on the chassis, ensuring it rotated freely and smoothly. Next, the primary drive gear was precisely attached to the motor's shaft, ensuring a snug and secure fit that would prevent slippage under load. Following this, the larger driven gears were then mounted onto the main axis, aligning them perfectly with the motor's gear. This meticulous alignment is paramount to prevent binding, reduce friction, and ensure efficient power transfer. The correct meshing of these gears is fundamental to converting the motor's rotational energy into the linear motion of the robot's wheels, dictating its speed and torque. This detailed assembly ensures a robust and efficient power transmission system, critical for the robot's mobility and performance on the competition field.



**Step 5:** Following the intricate assembly of the motor and gear system, our fifth crucial step involved the strategic placement of the Nihewo battery. To optimize the robot's stability and weight distribution, we carefully positioned the battery precisely at the geometric center of the first platform. This central location is vital for maintaining balance, especially during turns and rapid movements, preventing the robot from becoming top-heavy or prone to tipping. Furthermore, securing the battery in this location minimizes any potential interference with other components and ensures a clear pathway for wiring to the motor controller and other electronic modules. The choice of the Nihewo battery was based on its appropriate power output and capacity for our robot's operational requirements, providing the necessary energy for sustained performance throughout the competition. This deliberate placement significantly contributes to the overall stability and agility of our vehicle.



**Step 6:** With the first platform fully equipped and the battery optimally placed for stability, our sixth step involved constructing the critical second tier of our robot. This upper platform, meticulously designed and 3D-printed in-house to our precise specifications, serves as the dedicated space for our electronic components and future expansion modules. To secure it firmly above the first platform, we utilized four robust metal pillars. These pillars, which were part of the original Yahboom DIY Smart Robot Chassis Ackerman Chassis kit we acquired, provided the necessary height and structural integrity to create a stable, multi-tiered architecture. Each pillar was carefully aligned and screwed into place, connecting both platforms. This vertical expansion not only maximizes the available space within our robot's footprint but also creates a clear separation between the mechanical drive system on the lower level and the sensitive electronics on the upper level, simplifying wiring, minimizing electromagnetic interference, and facilitating easier access for debugging and maintenance.



**Step 7:** Finally, with the robot's structural foundation and power system established, our attention turned to integrating the "READY TO GO" electrical components and critical sensory input. On the second, meticulously 3D-printed platform, we strategically positioned all the necessary electronic modules, ensuring a clean and organized layout to facilitate future adjustments and prevent signal interference. This included the motor driver, microcontroller, and any other "plug-and-play" components required for immediate operation. Crucially, this stage also involved mounting the custom-designed stands for our ultrasonic sensors and the Pixy camera. The ultrasonic sensors are indispensable for providing real-time distance measurements to obstacles, allowing our robot to navigate its environment safely and effectively by detecting objects in its path. Meanwhile, the Pixy camera, a compact and powerful vision sensor, is integrated to enable advanced object recognition and tracking. This visual input is paramount for tasks such as identifying specific targets, following lines, or interpreting visual cues during the competition. The stands for these sensors were designed to ensure optimal viewing angles and stable positioning, maximizing their accuracy and effectiveness in perceiving the robot's surroundings. This comprehensive integration of electronics and sensors on the upper platform transforms the chassis from a mere frame into an intelligent, capable, and autonomous competition vehicle.



**IMPORTANT FINAL NOTE**

It's absolutely vital to clarify this point, as it underscores the true innovative spirit and engineering prowess of Team TNT. While it's true that we initially acquired a Yahboom DIY Smart Robot Chassis with Ackerman steering, it is crucial to understand that **this served merely as a foundational starting point, not a pre-assembled solution**. We fundamentally transformed over 80% of this initial chassis, effectively making it a completely unique and original creation.

Unlike "off-the-shelf" construction kits, such as those made by Lego, where components are designed for specific, pre-defined builds, our approach was one of genuine design and fabrication. We didn't simply follow instructions; we re-engineered. This involved a meticulous process of cutting, redesigning, and integrating custom 3D-printed parts that are entirely unique to KABOOM. From the custom motor stands and reinforced platforms to the precise placement of every electrical component, each modification was a deliberate engineering decision aimed at optimizing performance for the specific challenges of the WRO 2025 "Future Engineers" competition.

Our robot is a testament to hands-on problem-solving, iterative design, and the integration of diverse engineering disciplines. Every structural element and every electronic component was carefully selected, designed, or adapted to meet our specific needs, making KABOOM a truly bespoke robot. It's a product of our team's ingenuity, countless hours of design work, 3D printing, wiring, and rigorous testing – a far cry from simply assembling a kit. This deep level of customization and fabrication is what truly sets KABOOM apart as our own unique and original project.

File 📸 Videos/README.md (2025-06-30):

# Videos

In this directory you will find links to:
- Our Youtube channel.
- Videos of our previous prototypes, their circuits, and mechanisms.
- Videos of our final robot's circuits and mechanism.
- Demostrative videos that show our robot completing challenges and showing its speed and velocity.

## First challenge:
- Here we show Kaboom completing the 3 laps on the track.
- link: https://youtu.be/P82HiI01Nsc

## Second Challenge:

## Third Challenge:

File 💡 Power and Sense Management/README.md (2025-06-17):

# Power and sense management

In this directory we will talk about:

Tthe power source for the vehicle
- The sensors required to provide the vehicle with information to negotiate the different challenges
- Reasons for selecting various sensors and how they are being used on the vehicle together 
- Wiring diagram that includes all aspects of professional wiring diagrams
- Bill Of Materials (BOM)

Kaboom has one main power source. Our power is provided by a Nihewo Batery 11.1V/7500mAh, which is capable to provide energy to the whole vehicule, throgh out voltage regulators. The first regulator is the H-bridge, that will send power to the Arduino Board and the 11.4V JGB37-520 Motor. From the Arduino Board will be connected cables to the Pixy Cam and the two Ultrasonic Sensors. On the other side, to provide energy to the .4 V Servo Motor, we use a Buck Module, as our second regulator, so that we can lower the voltage input. In order, to turn the batteries (basically the robot) on and off, it counts with a switch (a power controller board) to do this.

These power sources for the vehicle, give power to whole robot, but some really important components that it gives power to are the sensors. Our robot counts with three sensors, two ultrasonic ones and one pixycam 2.1. The ultrasonic sensors help us detect the distance between the robot and the walls and/or obstacles, these two sensors are in each side of our robot. The pixycam 2.1 helps up detect colors in the Top front of the robot, it helps detect the red or/and green obstacles in the second challenge and the magenta parking lot in the track. 

We chose to have ultrasonic sensors in our robot because since they detect the distance between the robot and the walls/obstacles it helps us know how far or how close the robot is to these things. These is important because if the robot is close to the walls, for example, it turns (you can see these better explained in our code and in the `obstacle management` folder). If our robot didn't had any ultrasonic sensors it would 100% crash with the walls or obstacles in its way and wouldn't complete the challenges correctly. On the other hand, we chose to have a pixycam in the front of the robot, to the detect the colors of the things around the robot, this is also extremely helpful and important because, for example, in the rules of the WRO 2024 competition its established that if the robot sees a red obstacle it has to turn right, if we didn't had the pixycam we wouldn't be able to know the color of the obstacles in the track and would fail the challenge.

As you can see, the sensors are a very important part in the robot and eventhough they consumed a lot of power (because we have three of them) it is super worth it. 

Of course, for practicality and increased effectiveness, the sensors and the power sources are not connected directly to the our main controller, the Arduino Rev3 Board, instead, they are connected to a circuit which then connects to the board. For you to know what our circuit looks like and how it works we made a wiring diagram that includes all aspects of professional wiring diagrams, for a better comprehension:

|Wiring Diagrams|
|-----------|
||

The sensors and the power sources are not the only components and pieces we used in our robot, and are not the only important and expensive parts we used, so we also elaborated a Bill Of Materials (BOM). Below you can see it:

|Bill of Materials|
|-----------|
||

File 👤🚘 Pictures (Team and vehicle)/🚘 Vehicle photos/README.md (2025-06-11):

## Vehicle photos

In this directory, you will find all the photos related to our final robot:
- its circuits
- direction mechanism
- ultrasonic sensors

You can see this things in different angles and views:
- cenital views
- back views
- front views
- side views

(to know about how it works, what its made of, and everything related to our final robot, Kaboom, check all the folders and READMEs in this repository, except the `older versions of our final robot` folder, which talks about our previous prototypes and attempts, instead of our final robot)

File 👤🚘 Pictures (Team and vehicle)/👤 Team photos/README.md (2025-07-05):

# Team photos

In this directory you will find the photos of:
- each individual member of the team
- a photo of all the team members together

Our team counts with three members. We are:

1) Sarah Virginia Quintana Arrieta



2) Emiliana Raquel Guerrero Fermín



3) Nicola Pasquale Simone Perdomo



### And together we are TNT!

To make it easier to see us working, we created a YouTube video documenting our process for completing the first challenge.

YouTube link: https://youtu.be/CuEptmAdnrA

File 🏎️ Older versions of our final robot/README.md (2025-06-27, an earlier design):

 # Prototypes and sketches 

In this directory you will find all the information regarding our previous ideas and prototypes, their avantages and disavantages and the journey that lead to this prototypes. It is important to mention that we are going to focus here on the sketches and prototypes, not on the final robot (if you want to know more about our final robot, check the other folders like:`vehicle photos` folder, the `build` folder, etc. You can also read the README of this repository since we mainly talk about our final robot there and , as mentioned before, in the other folders except for this one).

- Now, _why is there a need to talk especifically about our sketches and prototypes?_

It is a need and an importance to talk about our sketches and prototypes because they have lead the way and gave us an incredible help for our final robot. They have shaped the way our final robot is today. It is important to have this in mind because, if you read "Our journey, progress and prototypes", you will see how it was a journey that started with a lot of downfalls but eventually we realized to learn from our mistakes and we recovered, making Terreneitor, our final robot.

## Sketches

Before we even started building the robot, we had a clear vision for what we wanted our robot to be like. We wanted a robot with 2 or 3 ultrasonic sensors (especially 2 in the front), the pixycam in the middle of the front of the robot (between the 2 ultrasonic sensors), to have 4 wheels (2 in the front, and 2 in the back like a real car), use 1 dc motor to move both back wheels, and have the batteries and arduino board behind the sensors (in the middle of the base). In the sketches below you can see these ideas reflected:

     

## First prototype 2024

After making the sketches for what we wanted our robot to look like, we started the construction by using lego pieces from the _MINDSTORMS education EV3_ lego set. As mentioned before, we wanted the both of the back wheels to move by using 1 dc motor who would move them simultaneously. 

### Step 0.1: 

In the beginning, we made the base really long, as you can see in the image below, but if you watch closely, you'll see at the end of the robot, the mechanism for the wheels which is mainly made by using gears (if you want to see how this mechanism works check the `videos` folder). On the other hand, in the front of the robot you'll see the direction mechanism which we later changed.



### Step 1:

After realizing it was too long, we shorten it as you can see in the photo below. You can also see the direction mechanism more clearly and see how we connected the dc motor to the wheels mechanism (when the motor was on, it moved the gray lego adapter who moved the gears and finally made the wheels move in unison, at the same time (this wheel mechanism didn't work on the ground because the dc motor didn't have enought strength and power to move the mechanism, plus the weight of all the robot was on top of it).



### Step 2:

In step 2, we changed the direction mechanism of the robot, opt in for a gear-based mechanism. You can also see how in this mechanism to move the gear we were using a dc motor instead of a servomotor.



### Step 3:

Here, you can see the direction mechanism mentioned in step 2 more clearly, this mechanism was supposed to work like this: The big gear moved the black piece below, making it go to either side. This mechanism, did not work (as you can see in the `videos` folder) because the gear wasn't strong enough to move the black piece, and another problem with this mechanism was that since we were using a dc motor instead of a servomotor it would move only to one side. You can also see how tall and big it has making it really heavy.



### Step 4:

In step 4, you can see the wheels mechanism from below the robot, you can see the gears, dc motor, and everything that belongs to this mechanism. 
You can also see the direction mechanism from below. And that we were using two small wheels in the front, and two bigger ones in the back.



### We learned many things from this prototype:

- It was heavy
- It was tall and big
- To not used a gear based direction mechanism
- Use a servomotor in the direction mechanism instead of a dc motor
- To use a simplier and light weight wheel mechanism so the dc motor can can power and make move on the ground

## Second prototype 2024

After we realized all the big problems our first prototype had, we decided to start again and build another prototype.

In the two pictures below, you can see how we applied our inical ideas we thought in the sketch: putting 2 ultrasonic sensors in the front of the robot and in between the pixycam. But if you see closely, you will see that it had no servomotor nor direction mechanism. So when the robot had to turn, one motor would be turn off and the other one will still be on, making it turn and they it would straight in a line and both motors will be turned on (if you want to know more about how this works check the `code` folder)

 

However, there was another problem, in the two images below you can see that for this prototype we had two dc motors, each one working for each wheel, but this violated the rules of the WRO 2024 competition so we had to change it eventually. You can also see the cicuit and how wide and big it was, which lead to the robot being very slow (you can see this in the `videos` folder)

 

### We learned many things from this prototype:

- It was still heavy
- It was very wide
- To obligatorily have a direction mechanism 
- To check and follow the rules of the WRO 2025 competition
- It was very slow

## Prototype 2025

|Angles of 1st Prototype 2025|Photo of Each:|
|---|---|
|Back view||
|Below view||
|Front View||
|Left-side view||
|Right-side view||
|Top view-1st Floor||
|Top view-2nd Floor||

After our first regional event at IEA on June 21, 2025, we decided to change the first floor of our chassis. The engineering factor wasn't clear, as it seemed like an "off-the-shelf kit." To fix this, we kept the front space (Ackerman system) from the prototype we got from the Ackerman Chassis we purchased. We then dismantled the rest of the metal pieces and screwed the front space onto other metal pieces we found. Finally, we painted the entire first floor black to make it homogeneous and decorated it with stickers to give the vehicle a fun perspective, rather than a darker one. To find photos of the official chassis, go to the file named "👤🚘 Pictures (Team and vehicle)" and then enter the "🚘 Vehicle photos" file.

After all this prototypes, we came to a conclusion: 

- We needed a robot that is:
  - Light weighted
  - Thin and tall
  - Have an ackerman steering system and use a servomotor in it
  - Follows the rules of the WRO 2025 competition
  - Has 1 motor that makes both wheels move simultaneously through an axis and gears, with a lot of traction 
  - Fast in speed

So with this in mind, we built our final robot, Kaboom, who has all of this characteristics and more.

(As stated at the beginning of this directory, if you want to know more about our final robot, check the other folders like:`vehicle photos` folder, the `build` folder, etc. You can also read the README of this repository since we mainly talk about our final robot there and in the other folders except for this one).

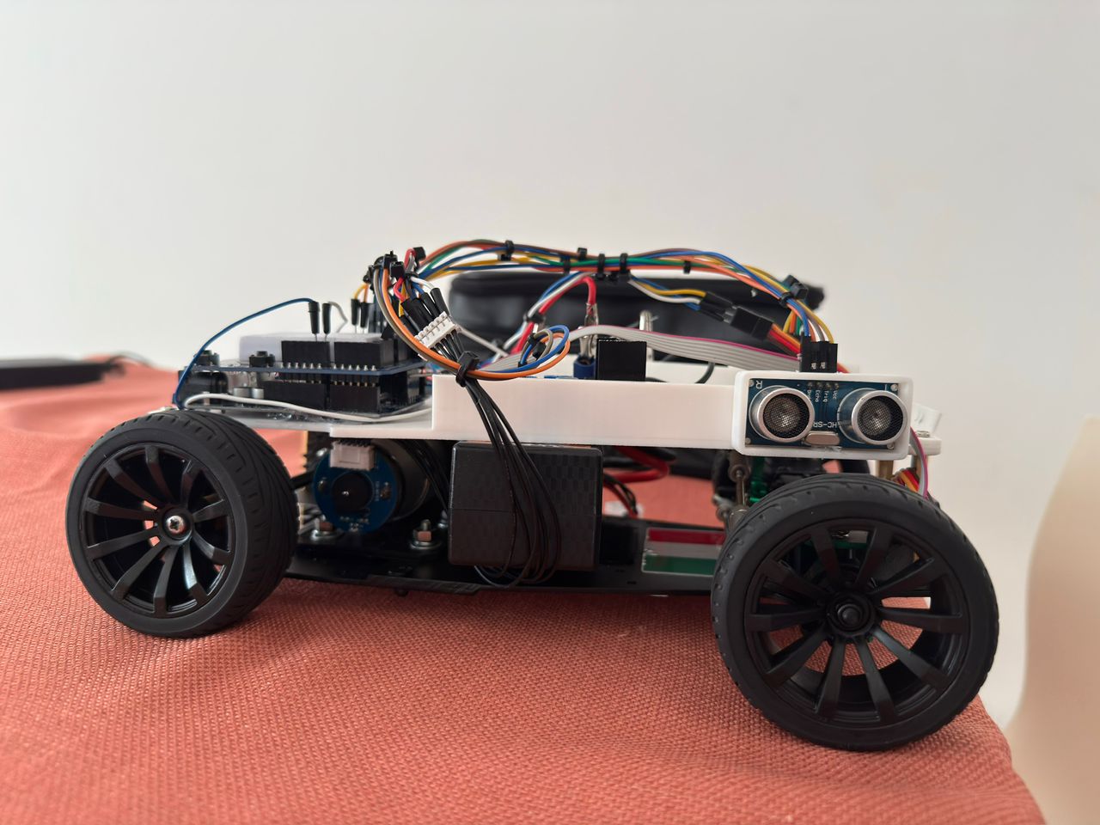
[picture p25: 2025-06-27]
👤🚘 Pictures (Team and vehicle)/🚘 Vehicle photos/Chassis 2025 (Right-side view).jpeg

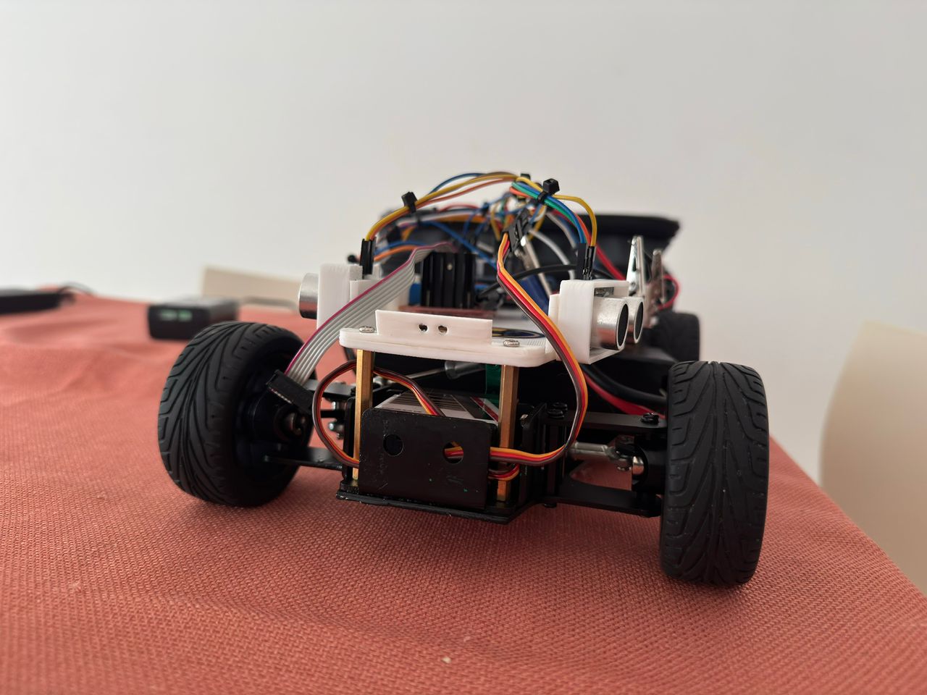
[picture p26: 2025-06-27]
👤🚘 Pictures (Team and vehicle)/🚘 Vehicle photos/Chassis 2025 (Front View).jpeg

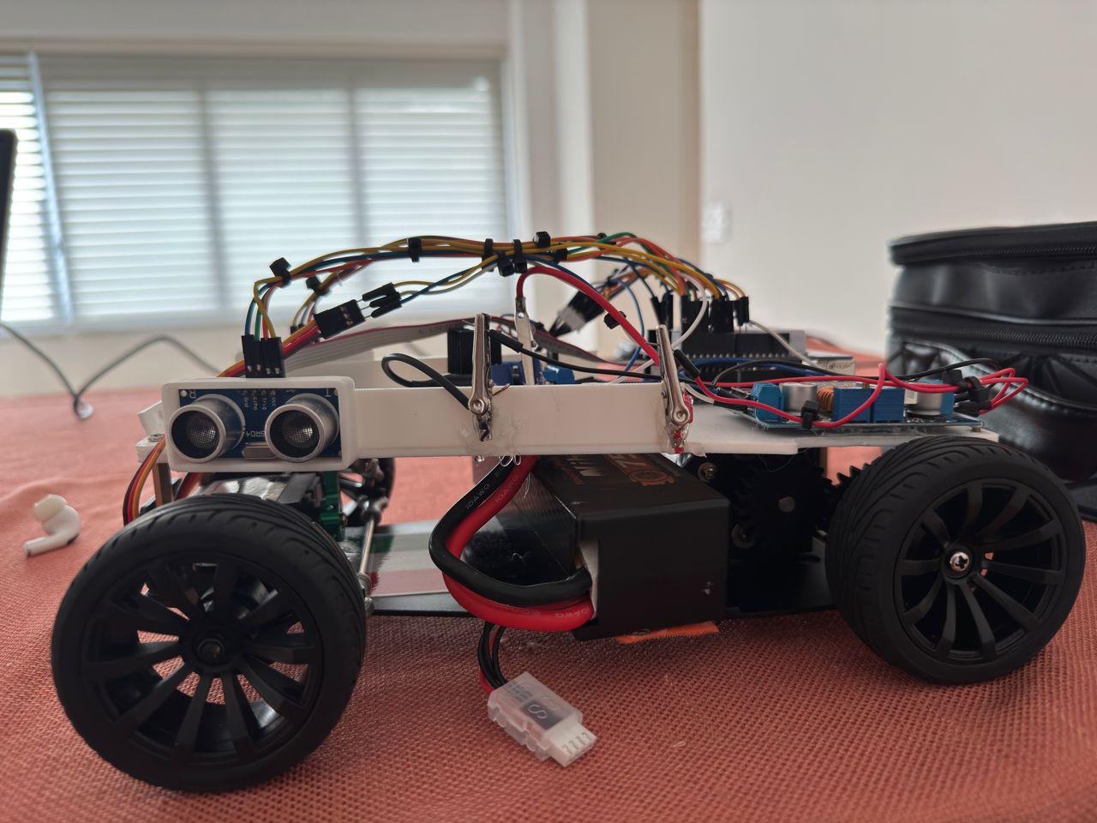
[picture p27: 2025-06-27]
👤🚘 Pictures (Team and vehicle)/🚘 Vehicle photos/Prototype Chassis 2025 (Left-side view).jpeg

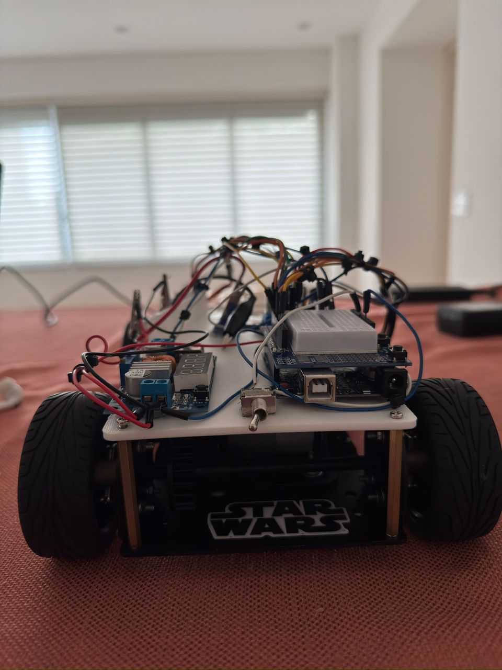
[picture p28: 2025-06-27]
👤🚘 Pictures (Team and vehicle)/🚘 Vehicle photos/Chassis 2025 (Back view).jpeg

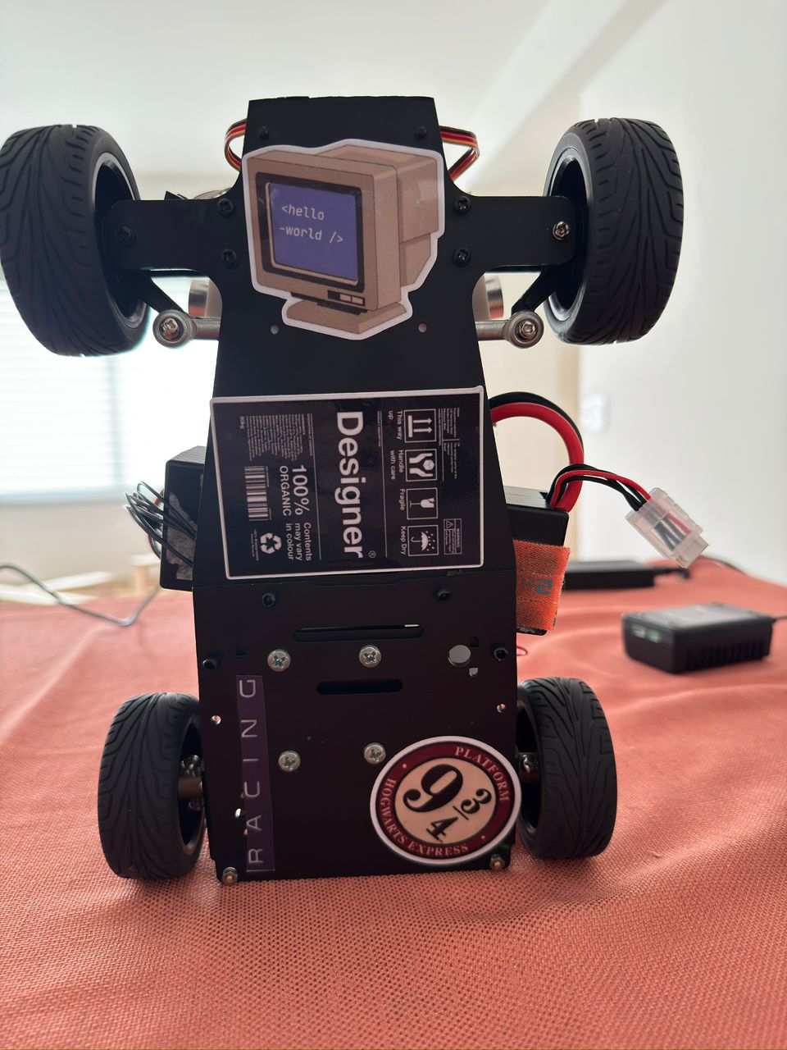
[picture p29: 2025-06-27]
👤🚘 Pictures (Team and vehicle)/🚘 Vehicle photos/Chassis 2025 (Below view).jpeg

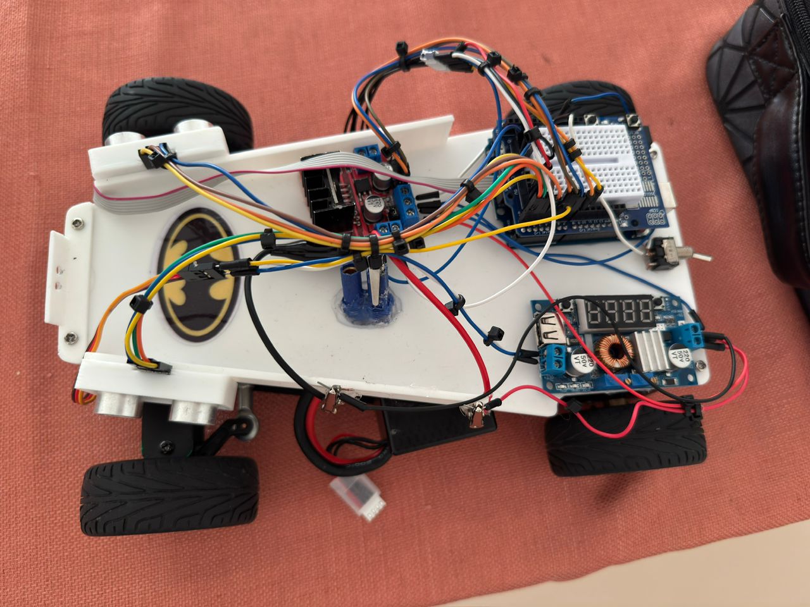
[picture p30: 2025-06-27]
👤🚘 Pictures (Team and vehicle)/🚘 Vehicle photos/Chassis 2025 (Top view-2nd Floor).jpeg

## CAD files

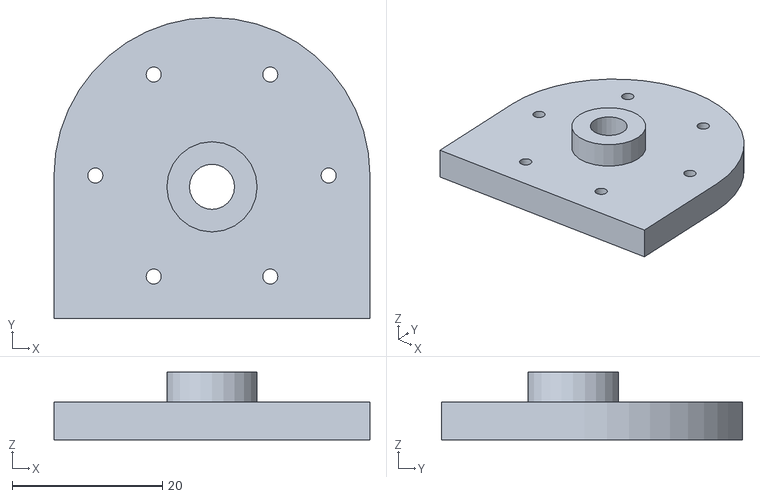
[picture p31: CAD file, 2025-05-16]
⚒️ Mobility management/Motor Support Stand 3d.stl
42.0 x 40.0 x 9.00

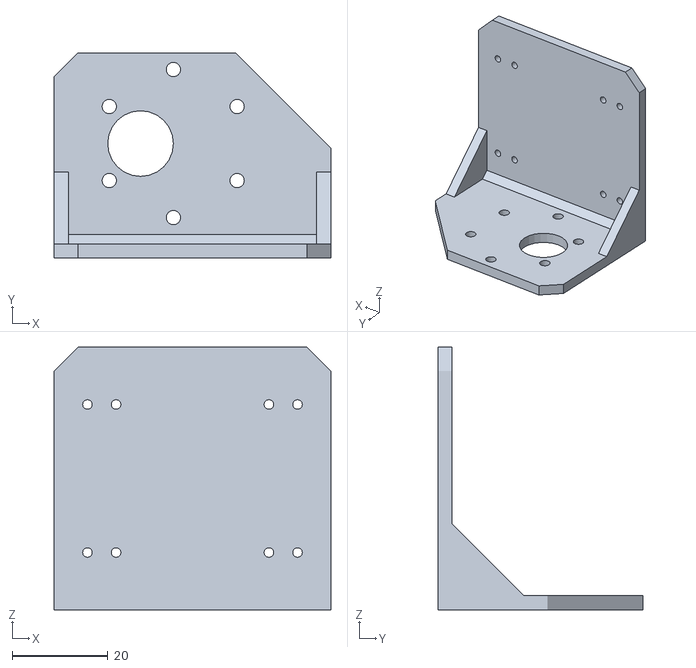
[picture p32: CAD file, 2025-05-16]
⚒️ Mobility management/ Motor Support 3d .stl
58.0 x 43.0 x 55.0

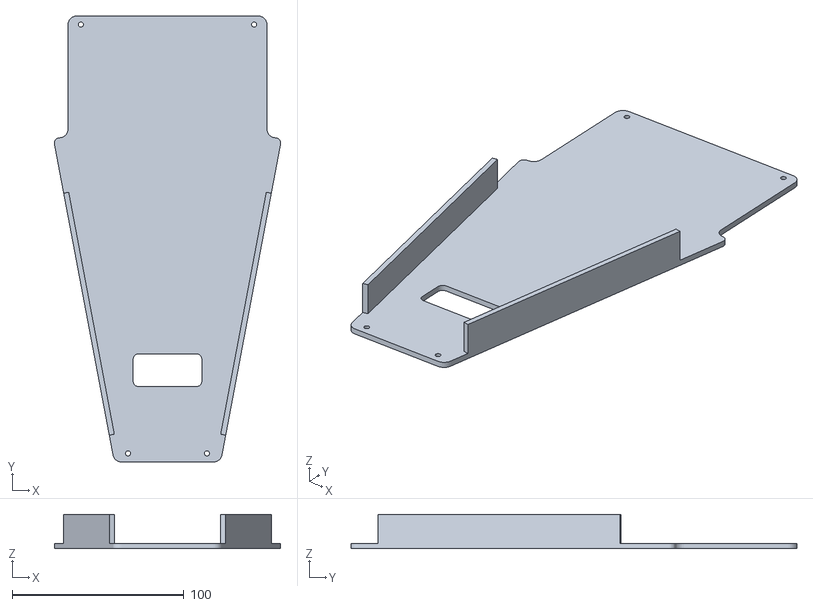
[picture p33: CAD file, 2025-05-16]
⚒️ Mobility management/2nd floor platform.stl
132.0 x 260.0 x 20.0

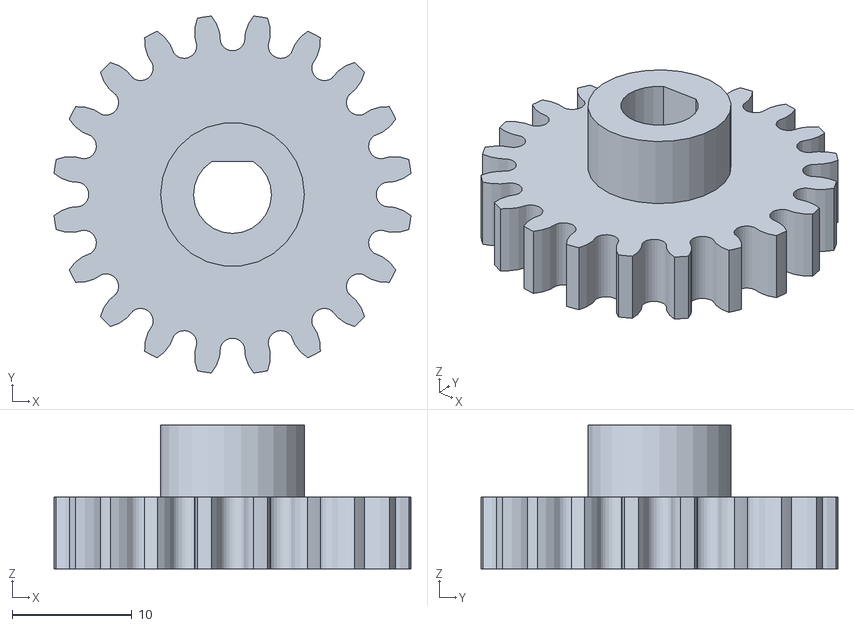
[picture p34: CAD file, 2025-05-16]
⚒️ Mobility management/Motor Gear.stl
29.8 x 29.8 x 12.0

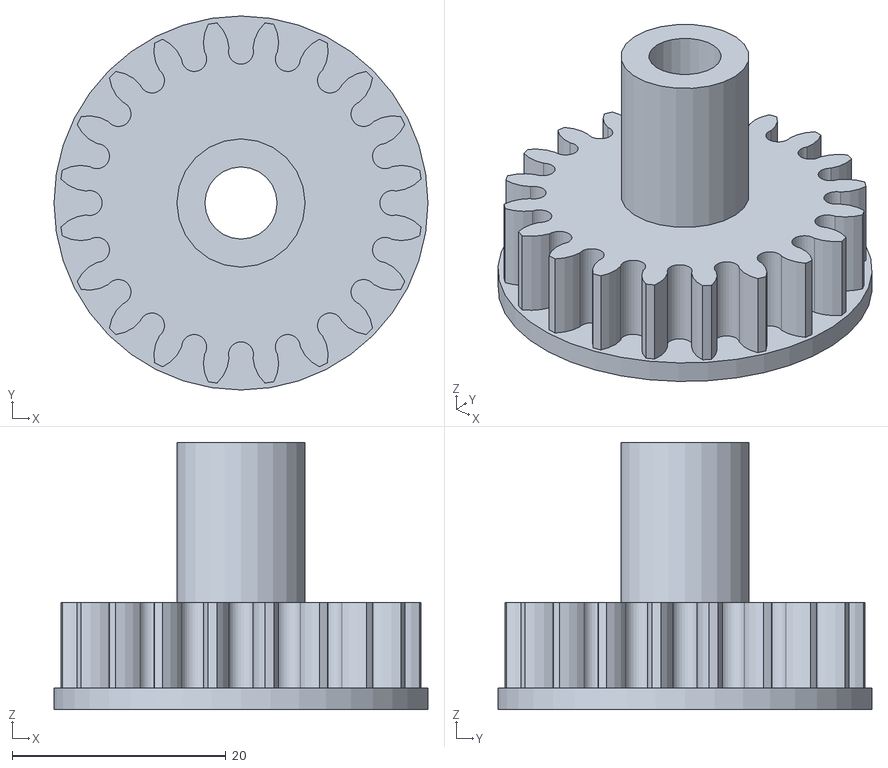
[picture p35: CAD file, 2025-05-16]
⚒️ Mobility management/Carriage Axle Gear 3d.stl
35.0 x 35.0 x 25.0

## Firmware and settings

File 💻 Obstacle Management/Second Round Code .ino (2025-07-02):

#include <Servo.h>
#include <Pixy2.h>

// ===== PIN DEFINITIONS =====
const int trigPin1 = 0;    // Left ultrasonic sensor
const int echoPin1 = 1;    
const int trigPin2 = 2;    // Right ultrasonic sensor
const int echoPin2 = 3;    
const int servoPin = 4;    // Steering servo
const int ENA = 5;         // Motor PWM
const int IN1 = 6;         // Motor IN1
const int IN2 = 7;         // Motor IN2

// ===== CONSTANTS =====
// Steering angles
#define LEFT_ANGLE 50      // Full left angle
#define RIGHT_ANGLE 131    // Full right angle
#define CENTER_ANGLE 85    // Center angle
#define LEFT_ANGLE_PIXY 50 // Left angle for Pixy
#define RIGHT_ANGLE_PIXY 132 // Right angle for Pixy

// Speed settings
#define NORMAL_SPEED 143   // Normal forward speed
#define TURN_SPEED 145     // Speed during turns
#define CORRECTION_SPEED 135 // Speed during wall correction
#define STOP_SPEED 0       // Stop speed

// Thresholds
#define WALL_THRESHOLD 180 // Distance threshold (cm)
#define WALL_CORRECTION_THRESHOLD 50 // Distance for wall correction (cm)
#define WALL_DIFFERENCE_THRESHOLD 30 // Minimum difference to trigger correction

// Timing
#define LEFT_TURN_DELAY 1200    // Left turn duration
#define RIGHT_TURN_DELAY 1050   // Right turn duration
#define LEFT_TURN_DELAY_PIXY 1000 // Left turn duration for Pixy
#define RIGHT_TURN_DELAY_PIXY 900 // Right turn duration for Pixy
#define CORRECTION_DELAY 200    // Wall correction duration

Pixy2 pixy;                   // Pixy2 camera object
Servo steeringServo;           // Steering servo
int turnCounter = 0;           // Counts completed turns
int lastCorrectionTime = 0;    // Tracks last wall correction time
int correctionCooldown = 1000; // Time between corrections

void setup() {
  // Configure pins
  pinMode(ENA, OUTPUT);
  pinMode(IN1, OUTPUT);
  pinMode(IN2, OUTPUT);
  pinMode(trigPin1, OUTPUT);
  pinMode(echoPin1, INPUT);
  pinMode(trigPin2, OUTPUT);
  pinMode(echoPin2, INPUT);

  // Initialize servo
  steeringServo.attach(servoPin);
  steeringServo.write(CENTER_ANGLE);
  
  // Start moving forward
  setMotorForward(NORMAL_SPEED);
  
  // Initialize Pixy camera
  pixy.init();
  pixy.setLamp(1, 1);
}

/**
 * Measures distance from ultrasonic sensor
 * @param trigPin Trigger pin
 * @param echoPin Echo pin
 * @return Distance in cm
 */
long measureDistance(int trigPin, int echoPin) {
  digitalWrite(trigPin, LOW);
  delayMicroseconds(2);
  digitalWrite(trigPin, HIGH);
  delayMicroseconds(10);
  digitalWrite(trigPin, LOW);
  return pulseIn(echoPin, HIGH, 30000) * 0.034 / 2;
}

/**
 * Sets motor to move forward at specified speed
 * @param speed Motor speed (0-255)
 */
void setMotorForward(int speed) {
  digitalWrite(IN1, LOW);
  digitalWrite(IN2, HIGH);
  analogWrite(ENA, speed);
}

/**
 * Sets motor to stop
 */
void setMotorStop() {
  digitalWrite(IN1, LOW);
  digitalWrite(IN2, LOW);
  analogWrite(ENA, STOP_SPEED);
}

/**
 * Performs wall correction based on sensor readings
 * @param leftDist Left sensor distance
 * @param rightDist Right sensor distance
 */
void performWallCorrection(int leftDist, int rightDist) {
  if (millis() - lastCorrectionTime < correctionCooldown) return;
  
  int difference = leftDist - rightDist;
  
  if (abs(difference) > WALL_DIFFERENCE_THRESHOLD) {
    if (difference > 0) {
      // Left wall is closer, adjust right
      steeringServo.write(CENTER_ANGLE + 15); // Small right adjustment
    } else {
      // Right wall is closer, adjust left
      steeringServo.write(CENTER_ANGLE - 15); // Small left adjustment
    }
    
    setMotorForward(CORRECTION_SPEED);
    delay(CORRECTION_DELAY);
    steeringServo.write(CENTER_ANGLE);
    lastCorrectionTime = millis();
  }
}

void loop() {
  // Read sensors
  int leftDist = measureDistance(trigPin1, echoPin1);
  delay(10); // Small delay between sensor readings
  int rightDist = measureDistance(trigPin2, echoPin2);
  
  // Check Pixy camera
  pixy.ccc.getBlocks();
  
  if (pixy.ccc.numBlocks) {
    int color = pixy.ccc.blocks[0].m_signature;
    
    if (color == 1) { // Green detected
      Serial.println("Green detected - turning left");
      steeringServo.write(LEFT_ANGLE_PIXY);
      setMotorForward(TURN_SPEED);
      delay(LEFT_TURN_DELAY_PIXY);
      steeringServo.write(CENTER_ANGLE);
      delay(200);
      setMotorForward(NORMAL_SPEED);
      delay(200);
    } 
    else if (color == 2) { // Red detected
      Serial.println("Red detected - turning right");
      steeringServo.write(RIGHT_ANGLE_PIXY);
      setMotorForward(TURN_SPEED);
      delay(RIGHT_TURN_DELAY_PIXY);
      steeringServo.write(CENTER_ANGLE);
      delay(250);
      setMotorForward(NORMAL_SPEED);
      delay(200);
    } 
    else if (color == 3) { // Special color
      Serial.println("Special color - counting turn");
      turnCounter++;
      delay(200);
    }
  } 
  else {
    // Check turn counter for final stop
    if (turnCounter >= 12) {
      setMotorForward(150);
      delay(500);
      setMotorStop();
      while (true); // Permanent stop
    }
    
    // Wall following logic
    if (leftDist < WALL_THRESHOLD && rightDist < WALL_THRESHOLD) {
      // Both walls detected - go straight
      steeringServo.write(CENTER_ANGLE);
      setMotorForward(NORMAL_SPEED);
    } 
    else if (leftDist > WALL_THRESHOLD) {
      // Left open - turn left
      steeringServo.write(LEFT_ANGLE);
      setMotorForward(TURN_SPEED);
      delay(LEFT_TURN_DELAY);
      steeringServo.write(CENTER_ANGLE);
      delay(200);
      setMotorForward(NORMAL_SPEED);
      delay(200);
    } 
    else if (rightDist > WALL_THRESHOLD) {
      // Right open - turn right
      steeringServo.write(RIGHT_ANGLE);
      setMotorForward(TURN_SPEED);
      delay(RIGHT_TURN_DELAY);
      steeringServo.write(CENTER_ANGLE);
      delay(250);
      setMotorForward(NORMAL_SPEED);
      delay(200);
    }
    
    // Wall correction logic
    if (leftDist < WALL_CORRECTION_THRESHOLD || rightDist < WALL_CORRECTION_THRESHOLD) {
      performWallCorrection(leftDist, rightDist);
    }
  }
}

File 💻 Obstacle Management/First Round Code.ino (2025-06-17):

#include <Servo.h>  // Include the Servo library to control servo motors

// Define pins for ultrasonic sensors
const int trigPin1 = 0, echoPin1 = 1;  // Sensor 1: trigger and echo pins
const int trigPin2 = 2, echoPin2 = 3;  // Sensor 2: trigger and echo pins

const int servoPin = 4;  // Pin for controlling the servo motor

// Motor control pins (H-bridge)
const int ENA = 2;       // Speed control pin (PWM)
const int IN1 = 0;       // Motor direction pin
const int IN2 = 1;       // Motor direction pin

// Servo angle definitions for different directions
#define LEFT 50          // Angle to turn left
#define CENTER 85        // Angle to go straight
#define RIGHT 121        // Angle to turn right

// Motor speed definitions
#define MAX_SPEED 200    // Normal forward speed
#define TURN_SPEED 230   // Speed when turning

// Distance threshold to decide when to turn
#define THRESHOLD 180    // If distance is greater than this, it's considered "clear"

// Delays used for turning
#define LEFT_DELAY 400   // Time needed to turn left
#define RIGHT_DELAY 322  // Time needed to turn right

#define COOLDOWN 160     // Wait time after turning to stabilize

Servo myServo;  // Create a servo object

unsigned long lastMeasurement = 0;     // Last time distance was measured
const int measurementInterval = 100;   // Time between measurements (ms)

int turnCount = 0;         // Counts how many turns have been made
bool isTurning = false;    // True if the robot is currently turning
unsigned long turnEndTime = 0; // Time when the cooldown ends

void setup() {
  Serial.begin(9600);          // Start serial communication for debug messages
  delay(300);                  // Allow time for Serial Monitor to initialize

  // Easter egg message printed once on startup
  Serial.println("================================");
  Serial.println("        Nico made this code      ");
  Serial.println("================================");

  pinMode(ENA, OUTPUT);        // Set motor speed pin as output
  pinMode(IN1, OUTPUT);        // Set motor direction pin as output
  pinMode(IN2, OUTPUT);        // Set motor direction pin as output

  pinMode(trigPin1, OUTPUT);   // Set trigger pin for sensor 1
  pinMode(echoPin1, INPUT);    // Set echo pin for sensor 1
  pinMode(trigPin2, OUTPUT);   // Set trigger pin for sensor 2
  pinMode(echoPin2, INPUT);    // Set echo pin for sensor 2

  myServo.attach(servoPin);    // Attach the servo motor
  myServo.write(CENTER);       // Point the servo straight ahead

  digitalWrite(IN1, LOW);      // Set motor direction forward
  digitalWrite(IN2, HIGH);
  analogWrite(ENA, MAX_SPEED); // Start moving forward at normal speed
}

// Function to measure distance using an ultrasonic sensor
long measureDistance(int trigPin, int echoPin) {
  digitalWrite(trigPin, LOW);         // Clear the trigger pin
  delayMicroseconds(2);
  digitalWrite(trigPin, HIGH);        // Send a 10 µs pulse
  delayMicroseconds(10);
  digitalWrite(trigPin, LOW);         // End the pulse

  // Measure echo time, convert to cm, return distance
  return pulseIn(echoPin, HIGH, 30000) * 0.034 / 2;
}

void loop() {
  unsigned long now = millis();  // Get current time

  // If turning and cooldown hasn't finished, skip this cycle
  if (isTurning && now < turnEndTime) {
    return;
  }
  // Cooldown finished, resume measurements
  else if (isTurning && now >= turnEndTime) {
    isTurning = false;
  }

  // Time to take a new measurement
  if (now - lastMeasurement >= measurementInterval) {
    lastMeasurement = now;

    // Measure distance from both sensors
    int distLeft = measureDistance(trigPin1, echoPin1);
    delay(5);  // Small delay between readings
    int distRight = measureDistance(trigPin2, echoPin2);

    // If both sides are blocked
    if (distLeft < THRESHOLD && distRight < THRESHOLD) {
      myServo.write(CENTER);  // Keep going straight
    }
    // If the right side is clear
    else if (distRight > THRESHOLD) {
      myServo.write(RIGHT);             // Turn right
      digitalWrite(IN1, LOW);           // Set motor forward
      digitalWrite(IN2, HIGH);
      analogWrite(ENA, TURN_SPEED);     // Increase speed for turning
      delay(RIGHT_DELAY);               // Time to turn
      turnCount++;                      // Count the turn
      isTurning = true;                 // Enter cooldown
      turnEndTime = millis() + COOLDOWN;
    }
    // If the left side is clear
    else if (distLeft > THRESHOLD) {
      myServo.write(LEFT);              // Turn left
      digitalWrite(IN1, LOW);           // Set motor forward
      digitalWrite(IN2, HIGH);
      analogWrite(ENA, TURN_SPEED);     // Increase speed for turning
      delay(LEFT_DELAY);                // Time to turn
      turnCount++;                      // Count the turn
      isTurning = true;                 // Enter cooldown
      turnEndTime = millis() + COOLDOWN;
    }
    // Default case: go straight
    else {
      myServo.write(CENTER);
    }

    // Stop the robot after 24 turns
    if (turnCount == 24) {
      digitalWrite(IN1, LOW);
      digitalWrite(IN2, LOW);
      analogWrite(ENA, 0);
      while (true) { delay(1000); }     // Stay stopped forever
    }

    // Resume normal movement
    digitalWrite(IN1, LOW);
    digitalWrite(IN2, HIGH);
    analogWrite(ENA, MAX_SPEED);
  }
}

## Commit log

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2025-05-07 Rename Third prototype to Third prototype (cenital view)
2025-05-17 Rename prueba_1.stl to motor try on support.stl
    [motor try on support.stl]
2025-05-17 Rename plataforma.stl to 1st floor platform
2025-05-17 Rename 1st floor platform to 1st floor platform.stl
    [1st floor platform.stl]
2025-05-17 Rename 1st floor platform.stl to 2nd floor platform.stl
    [2nd floor platform.stl]
2025-05-17 Rename chasis .jpg to chassis .jpg
2025-05-17 Rename engranaje_eje.stl to motor gear.stl
    [motor gear.stl]
2025-05-17 Rename motor gear.stl to carriage axel gear.stl
    [carriage axel gear.stl]
2025-05-17 Rename engranaje_motor.stl to motor gear.stl
    [motor gear.stl]
2025-05-17 Rename soporte.stl to motor support.stl
    [motor support.stl]
2025-05-17 Rename soporte_3.stl to motor support 2.stl
    [motor support 2.stl]
2025-05-17 Rename soporte_motor.stl to motor support 3.stl
    [motor support 3.stl]
2025-05-17 Rename shield protoboard arduino .webp to shield protoboard arduino .stl
    [shield protoboard arduino .stl]
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2025-06-09 Rename cables2.jpg to Alligator Cables.jpg
2025-06-09 Rename motor support 3.stl to Motor Support Stand 3d.stl
    [Motor Support Stand 3d.stl]
2025-06-09 Rename Motor Support Stand 3d.stl to Motor Support 3d.stl
    [Motor Support 3d .stl]
2025-06-09 Rename motor support 2.stl to Motor Support Stand 3d.stl
    [Motor Support Stand 3d.stl]
2025-06-09 Rename motor gear.stl to Motor Gear.stl
    [Motor Gear.stl]
2025-06-09 Rename arduino shield protoboard .jpg to Arduino Shield Protoboard .jpg
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2025-06-09 Rename arduino-uno-r3-atmega-dip-328p-chip-grde.jpeg to Arduino UNO.jpeg
2025-06-09 Rename cables.png to Arduino Cables.png
2025-06-09 Rename carriage axel gear.stl to Carriage Axel Gear 3d.stl
    [Carriage Axel Gear 3d.stl]
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2025-06-11 Rename WhatsApp Image 2025-06-10 at 18.36.55.jpeg to Chassis 2025 (Back view).jpeg
2025-06-11 Rename Chasis 2025 (Left-side view).jpeg to Chassis 2025 (Left-side view).jpeg
2025-06-11 Rename Chasis 2025 (Front View).jpeg to Chassis 2025 (Front View).jpeg
2025-06-11 Rename WhatsApp Image 2025-06-10 at 18.36.56 (1).jpeg to Chassis 2025 (Top view-2nd Floor).jpeg
2025-06-11 Rename WhatsApp Image 2025-06-10 at 18.36.56 (2).jpeg to Chassis 2025 (Top view-1st).jpeg
2025-06-11 Rename WhatsApp Image 2025-06-10 at 18.36.56.jpeg to Chassis 2025 (Right-side view).jpeg
2025-06-11 Rename WhatsApp Image 2025-06-10 at 18.36.54.jpeg to Chassis 2025 (Below view).jpeg
2025-06-12 Rename New flowchart diagram TNT..png to Flowchart diagram TNT 2024..png
2025-06-12 Rename Old flowchart diagram TNT.jpeg to 1st Old flowchart diagram TNT2024.jpeg
2025-06-12 Rename Flowchart diagram TNT 2024..png to 2nd Old flowchart diagram TNT2024.jpeg
2025-06-16 Rename Carriage Axel Gear 3d.stl to Carriage Axle Gear 3d.stl
    [Carriage Axle Gear 3d.stl]
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2025-06-17 Rename Lambú Labs P1s .jpg to Lambu Labs P1s .jpg
2025-06-26 Rename 👤🚘 Pictures (Team and vehicle)/🚘 Vehicle photos/Chassis 2025 (Back view).jpeg to 🏎️ Older versions of our final robot/1st Prototype Chassis 2025 (Back view).jpeg
2025-06-26 Rename 👤🚘 Pictures (Team and vehicle)/🚘 Vehicle photos/Chassis 2025 (Below view).jpeg to 🏎️ Older versions of our final robot/1st Prototype Chassis 2025 (Below view).jpeg
2025-06-26 Rename 👤🚘 Pictures (Team and vehicle)/🚘 Vehicle photos/Chassis 2025 (Front View).jpeg to 🏎️ Older versions of our final robot/1st Prototype Chassis 2025 (Front View).jpeg
2025-06-26 Rename 👤🚘 Pictures (Team and vehicle)/🚘 Vehicle photos/Chassis 2025 (Left-side view).jpeg to 🏎️ Older versions of our final robot/1st Prototype Chassis 2025 (Left-side view).jpeg
2025-06-26 Rename 👤🚘 Pictures (Team and vehicle)/🚘 Vehicle photos/Chassis 2025 (Right-side view).jpeg to 🏎️ Older versions of our final robot/1st Prototype Chassis 2025 (Right-side view).jpeg
2025-06-26 Rename 👤🚘 Pictures (Team and vehicle)/🚘 Vehicle photos/Chassis 2025 (Top view-1st).jpeg to 🏎️ Older versions of our final robot/1st Prototype Chassis 2025 (Top view-1st).jpeg
2025-06-27 Rename 👤🚘 Pictures (Team and vehicle)/🚘 Vehicle photos/Chassis 2025 (Top view-2nd Floor).jpeg to 🏎️ Older versions of our final robot/1st Prototype Chassis 2025 (Top view-2nd Floor).jpeg
2025-06-27 Rename WhatsApp Image 2025-06-26 at 17.45.03 (1).jpeg to Chassis 2025 (Below view).jpeg
2025-06-27 Rename WhatsApp Image 2025-06-26 at 17.45.03.jpeg to Chassis 2025 (Back view).jpeg
2025-06-27 Rename WhatsApp Image 2025-06-26 at 17.45.04 (1).jpeg to Chassis 2025 (Top view-2nd Floor).jpeg
2025-06-27 Rename WhatsApp Image 2025-06-26 at 17.45.04 (2).jpeg to Chassis 2025 (Front View).jpeg
2025-06-27 Rename WhatsApp Image 2025-06-26 at 17.45.04.jpeg to Chassis 2025 (Right-side view).jpeg
2025-06-27 Rename WhatsApp Image 2025-06-26 at 17.45.05.jpeg to Prototype Chassis 2025 (Left-side view).jpeg
2025-06-27 Rename Prototype Chassis 2025 (Left-side view).jpeg to Chassis 2025 (Left-side view).jpeg
2025-06-30 Update Code for the servomotor and ultrasonic sensors.ino
